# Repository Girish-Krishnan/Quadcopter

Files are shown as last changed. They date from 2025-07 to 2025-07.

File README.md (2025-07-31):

# Quadcopter

*Made by Girish Krishnan and Anish Kulkarni*

---

Open-source hardware and firmware for a compact 4‑rotor UAV.
[**Watch the demo videos on YouTube!**](https://www.youtube.com/playlist?list=PLE_L-WPduPxbYMuvPQKa1v5fUpK1VIxrP)

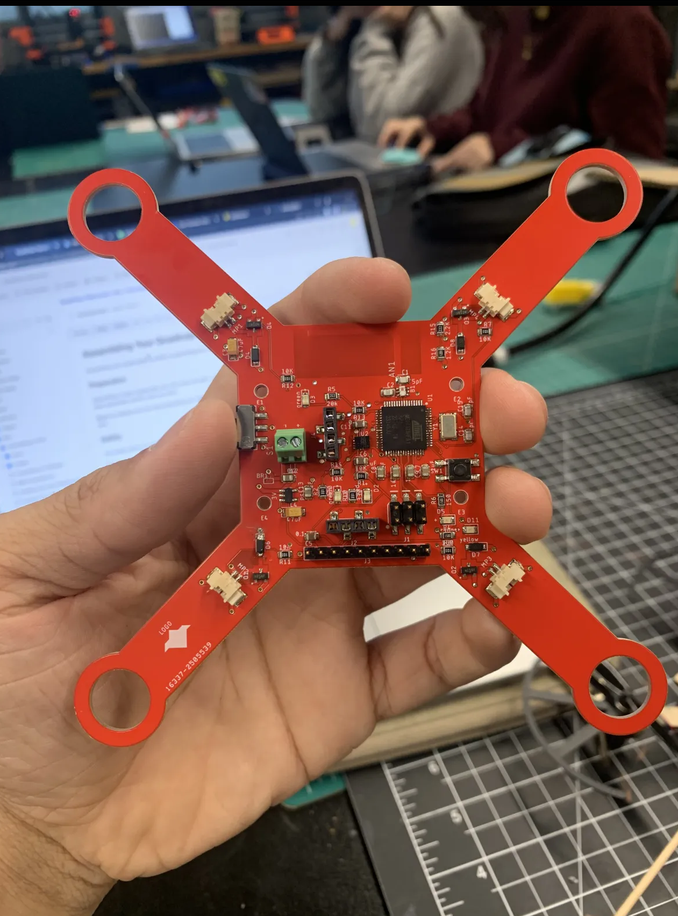
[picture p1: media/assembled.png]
Assembled Quadcopter
|PID Tuning Animation| |
|---|---|

This project contains hardware and firmware for a custom 4‑rotor UAV. The design is based on the ATmega128RFA1 microcontroller which integrates a 2.4 GHz radio. The repository includes the printed circuit board layout, flight controller firmware, and code for a handheld remote.

## Table of Contents
- [Quadcopter](#quadcopter)
  - [Table of Contents](#table-of-contents)
  - [Features](#features)
  - [System Overview](#system-overview)
  - [Repository Layout](#repository-layout)
  - [Hardware Overview](#hardware-overview)
  - [Firmware Overview](#firmware-overview)
    - [Wireless Protocol](#wireless-protocol)
    - [Flight Controller (`quad_flight.ino`)](#flight-controller-quad_flightino)
    - [Remote Firmware (`remote_firmware.ino`)](#remote-firmware-remote_firmwareino)
    - [PID Control Loops](#pid-control-loops)
  - [Building and Uploading](#building-and-uploading)
  - [License](#license)
  - [References](#references)

## Features
- Flight controller based on the ATmega128RFA1 with integrated 2.4 GHz radio
- Handheld remote with dual gimbals, LCD and menu navigation
- Telemetry link for battery monitoring and state feedback
- PID tuning directly from the remote
- Four-layer PCB with on-board ESC drivers and IMU

## System Overview

The project consists of two main pieces of hardware:

1. **Quadcopter** – a compact flight controller board driving four brushless motors via electronic speed controllers (ESCs).
2. **Remote** – a handheld transmitter with gimbal sticks, buttons and an LCD that sends pilot commands over 2.4 GHz.

The diagram below summarizes the high–level flow of data and control.

```mermaid
graph LR
    Remote[(Handheld Remote)] -- 2.4GHz --> MCU[ATmega128RFA1]
    MCU --> IMU[LSM6DSOX IMU]
    MCU --> ESCs
    ESCs --> Motors
    MCU -- Telemetry --> Remote
```

## Repository Layout

```
firmware/              Embedded source code and Arduino libraries
hardware/              EAGLE schematic/board files and CAM outputs
```

Key firmware sketches:

- `quad_flight/quad_flight.ino` – flight controller running on the quadcopter
- `remote_firmware/remote_firmware.ino` – transmitter with LCD and gimbals

## Hardware Overview

The quadcopter PCB is a four‑layer board measuring 119×119 mm with red soldermask and white silkscreen【F:hardware/metadata.txt†L1-L4】. Major components:

- **ATmega128RFA1** MCU with onboard 2.4 GHz transceiver
- **LSM6DSOX** IMU for 3‑axis gyro and accelerometer
- FET motor drivers for four brushless ESCs
- Power regulation, battery monitor (via `BAT_SENSE_PIN`), and status LEDs
- Connectors for an external receiver and programming headers

EAGLE design files are under `hardware/` and the manufacturing CAM outputs are zipped as `quadcopter.cam.zip`.

The `hardware/QuadClass_Atmega128RFA_Arduino_Addon` folder contains board definitions so the Arduino IDE can program the ATmega128RFA1 board. Copy this directory into the `hardware` folder of your Arduino sketchbook to install the board support.

Here is a schematic overview of the quadcopter:

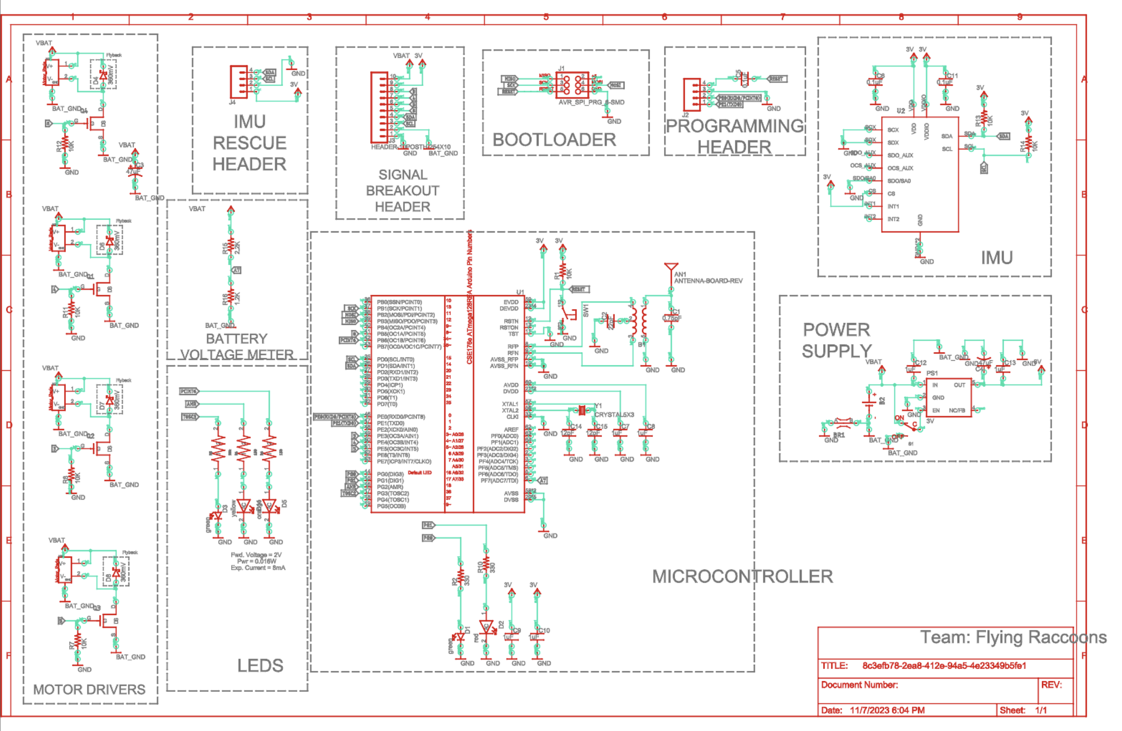
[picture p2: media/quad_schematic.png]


Here is the layout of the quadcopter PCB, showing the placement of components and routing:

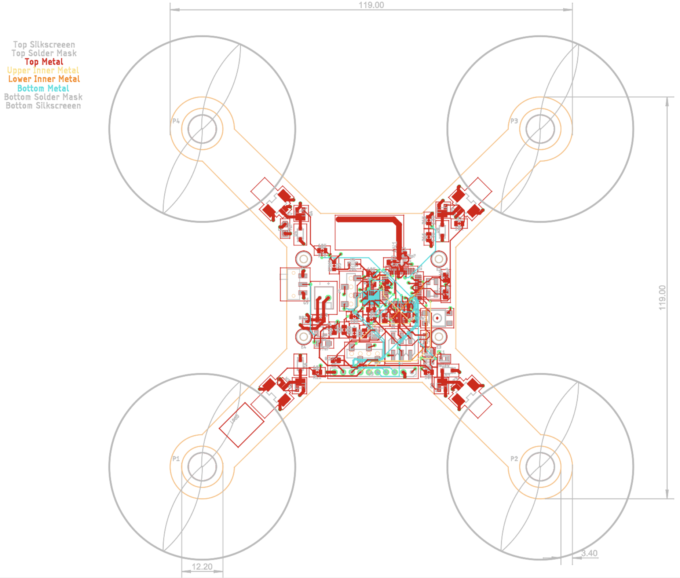
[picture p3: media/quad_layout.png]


Here are pictures of the top and bottom layers of the PCB:

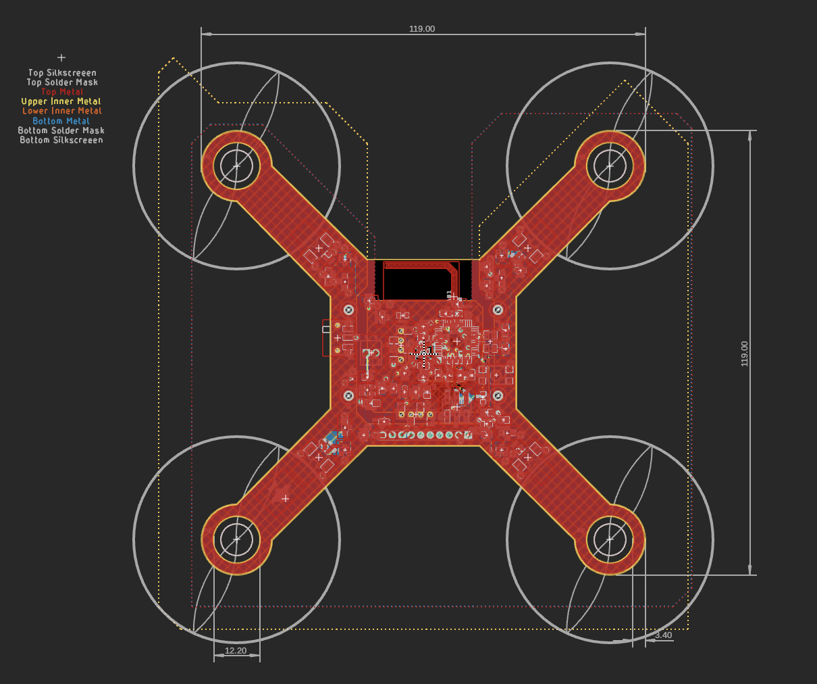
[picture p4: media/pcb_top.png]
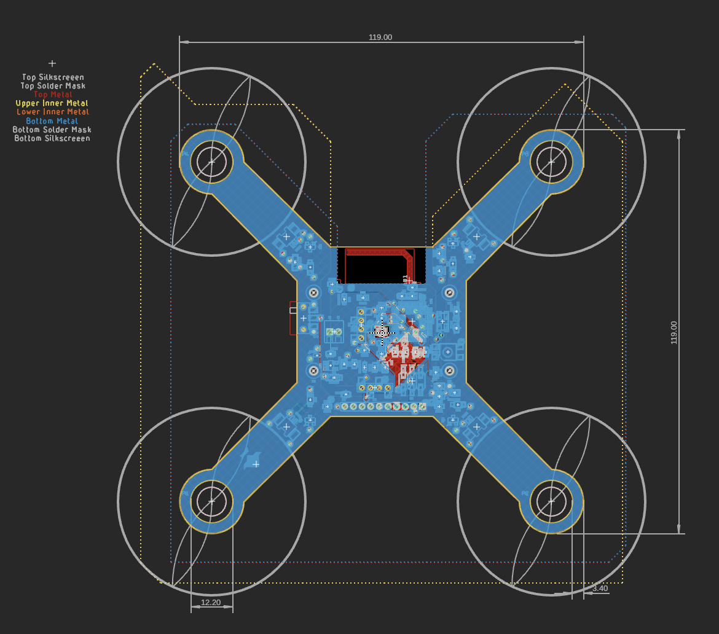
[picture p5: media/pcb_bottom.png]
|||
|---|---|
| Top Layer | Bottom Layer |

## Firmware Overview

### Wireless Protocol

The on-board radio communicates with the remote using packets defined in `Wireless_Packet.h`:

```cpp
struct Packet {
    uint8_t magicNumber;
    uint8_t roll, pitch, yaw, throttle;
    double  Kp_pitch, Ki_pitch, Kd_pitch;
    double  Kp_roll,  Ki_roll,  Kd_roll;
    double  Kp_yaw,   Ki_yaw,   Kd_yaw;
    uint8_t batteryVoltage;
    int     trims[3];
    uint8_t state;
    uint8_t checksum;
};
```
【F:firmware/libraries/Wireless_Packet/Wireless_Packet.h†L1-L34】

Packets carry user commands, PID gains, trims, and telemetry such as battery level. Communication occurs on channel&nbsp;20 by default.

### Flight Controller (`quad_flight.ino`)

The flight controller reads the LSM6DSOX IMU using the Adafruit AHRS library. A complementary filter and PID loop produce motor outputs:

- Desired roll/pitch/yaw are received from the remote.
- IMU data is converted to angles and rates.
- Proportional, integral and derivative terms are computed every loop.
- Four PWM outputs drive the motors via `spinMotors()` which mixes PID outputs to each rotor.

State transitions (`DISARMED`, `ARMED`, `QUAD_RESET`) are received wirelessly. The code also reports back battery percentage every second.

### Remote Firmware (`remote_firmware.ino`)

The remote uses analog gimbals, push buttons, a rotary encoder and a SerLCD display. It calibrates the joystick range to map raw ADC values to 0–255 and stores them in EEPROM【F:firmware/remote_firmware/remote_firmware.ino†L240-L314】. In the armed state, pressing the encoder or buttons adjusts trim values which are sent in each packet.

Incoming packets from the quad provide its state and battery status so the remote can display feedback to the user.

The remote hardware exposes the following controls:

- Two gimbal sticks (yaw/throttle and roll/pitch) wired to analog inputs A0–A3.
- A rotary encoder with push‑button for menu navigation.
- Five directional buttons for trims and menu actions.
- A small serial LCD showing mode and battery levels.

All pins are defined in `quad_remote.h` under the `Remote` library.

### PID Control Loops

Here is the setup used for tuning the PID for the roll and pitch axes:

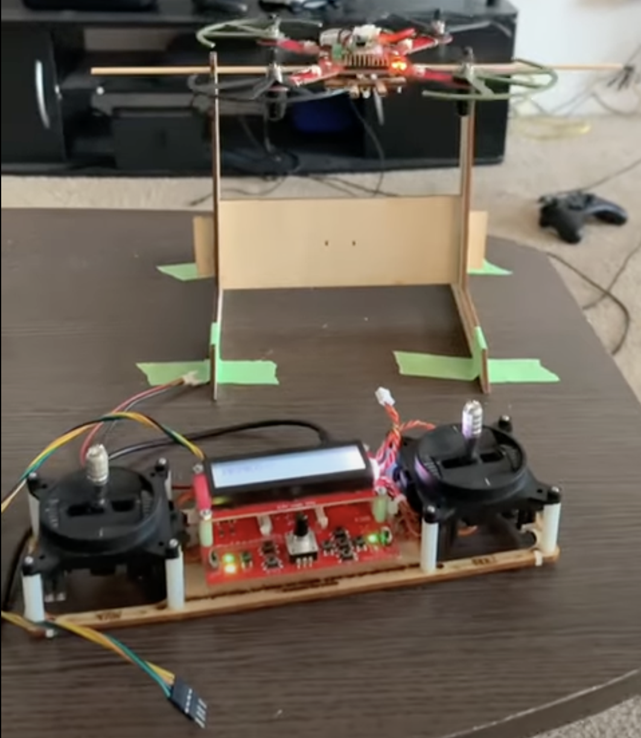
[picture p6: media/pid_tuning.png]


The flight controller stabilizes the aircraft using three independent PID loops
for roll, pitch and yaw. Error values are computed from the difference between
the desired setpoint (received from the remote) and the measured angle or rate
from the IMU. Each loop produces a correction that is mixed into the individual
motor commands.

```mermaid
graph TD
    R[Remote input] -->|setpoint| E[Error]
    IMU -- feedback --> E
    E --> P[P gain]
    E --> I[I gain]
    E --> D[D gain]
    P --> SUM
    I --> SUM
    D --> SUM
    SUM --> MIX(Motor Mixer)
    MIX --> Motors
```

## Building and Uploading

1. Install the Arduino IDE.
2. Copy `firmware/hardware/QuadClass_Atmega128RFA_Arduino_Addon` to your Arduino `hardware/` directory and restart the IDE. Select **Quad Class ATmega128RFA1 Boards** under *Tools → Board*.
3. Copy the libraries from `firmware/libraries` into your Arduino `libraries/` directory.
4. Open `firmware/quad_flight/quad_flight.ino` to build the flight controller or `firmware/remote_firmware/remote_firmware.ino` for the remote.
5. Connect the ATmega128RFA1 board via USB and upload using the standard Arduino bootloader.

## License

This project is released under the MIT License; see [LICENSE](LICENSE) for details.

## References

- [NVSL QuadClass Resources](https://github.com/NVSL/QuadClass-Resources/tree/master)

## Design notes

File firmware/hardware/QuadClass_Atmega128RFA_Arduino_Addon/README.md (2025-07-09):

# Arduino Board definitions for the ATmega128RFA1-based boards

This folder should be added to a *hardware* directory within your Arduino sketchbook. Normally the sketchbook will install to your documents/Arduino folder. If a *hardware* folder isn't already there, make it.

This directory contains a *boards.txt* file which defines how Arduino will handle ATmega128RFA1-based boards for the Quadcopter Class, and adds a selectable option under the *Tools > Board* menu. When you open the Arduino ID (close and reopen if it's already open), this option should be added to the menu.

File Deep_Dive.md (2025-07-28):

# Quadcopter Deep Dive

## Overview

This project implements an open‑source four‑rotor UAV platform. The repository contains the complete firmware for both flight controller and remote as well as hardware designs for the custom PCB. The microcontroller at the heart of both devices is the Atmel ATmega128RFA1 which integrates a 2.4&nbsp;GHz radio allowing wireless control and telemetry.

The codebase is organized under `firmware/` for all sketches and reusable libraries while `hardware/` holds EAGLE board/schematic files. The root [README](README.md) provides a high‑level summary and diagrams of the system architecture. Key highlights include support for PID tuning via the remote and telemetry reporting from the quadcopter back to the handheld controller.

This document dives into the design and implementation details of the project, covering hardware features, data structures, algorithms, and how the pieces interact.

## Hardware Design

### Board Metadata

The quadcopter PCB is a four‑layer board with dimensions of 119&nbsp;×&nbsp;119&nbsp;mm using red soldermask and white silkscreen as recorded in `hardware/metadata.txt`:

```text
Color: Red
Silkscreen colors: White
Dimensions: 119mm x 119mm
```
【F:hardware/metadata.txt†L1-L4】

### Major Components

* **ATmega128RFA1** – integrates an AVR CPU with a low‑power 2.4&nbsp;GHz transceiver.
* **LSM6DSOX IMU** – provides 3‑axis gyroscope and accelerometer data.
* FET motor drivers for the four ESC channels.
* Battery monitor on analog pin `BAT_SENSE_PIN`.
* Status LEDs and programming connectors.

The board and schematic files (`quadcopter.sch`, `quadcopter.brd`) can be opened in EAGLE for detailed component placement and routing inspection.

## Firmware Structure

The `firmware/` directory contains a number of Arduino sketches:

```
RFChat/        – radio terminal test
RFCount/       – simple counting transmitter
RFEcho/        – echo received bytes
RFPing/        – radio link ping utility
quad_flight/   – flight controller running on the quadcopter
remote_firmware/ – code for the handheld remote
libraries/     – shared driver libraries
```

The two primary sketches used in normal operation are `quad_flight/quad_flight.ino` and `remote_firmware/remote_firmware.ino`. Several custom libraries are included under `firmware/libraries` to abstract radio access, sensor fusion and user input.

### Wireless Packet Protocol

Both sides communicate using a packed C++ struct defined in `Wireless_Packet.h`. Every field of the struct is transmitted over the air, preceded by a magic number and followed by a checksum. The struct layout is reproduced in the README and in the header file:

```cpp
struct Packet {
    uint8_t magicNumber;
    uint8_t roll;
    uint8_t pitch;
    uint8_t yaw;
    uint8_t throttle;
    double Kp_pitch;
    double Ki_pitch;
    double Kd_pitch;
    double Kp_roll;
    double Ki_roll;
    double Kd_roll;
    double Kp_yaw;
    double Ki_yaw;
    double Kd_yaw;
    uint8_t batteryVoltage;
    int trims[3];
    uint8_t state;
    uint8_t checksum;
};
```
【F:firmware/libraries/Wireless_Packet/Wireless_Packet.h†L17-L36】

Two constants distinguish packet origin: `MAGIC_NUMBER_REMOTE` (`223`) and `MAGIC_NUMBER_QUAD` (`154`). The library provides a simple API consisting of `sendPacket`, `receivePacket`, and `calculateChecksum`. `receivePacket` reads bytes from the radio and verifies both checksum and magic number before returning:

```cpp
void Wireless_Packet::sendPacket(const Packet &packet) {
    rfWrite((uint8_t *)&packet, sizeof(Packet));
}

bool Wireless_Packet::receivePacket(Packet &packet, bool isRemote) {
    bool verify = false;
    if (rfAvailable() >= sizeof(Packet)) {
        rfRead((uint8_t *)&packet, sizeof(Packet));
        uint8_t checksum = calculateChecksum(packet);
        uint8_t magicNumber = packet.magicNumber;
        if (isRemote)
            verify =  (checksum == packet.checksum) && (magicNumber == MAGIC_NUMBER_QUAD);
        else
            verify =  (checksum == packet.checksum) && (magicNumber == MAGIC_NUMBER_REMOTE);
    }
    if (!verify) {
        rfFlush();
    }
    return verify;
}
```
【F:firmware/libraries/Wireless_Packet/Wireless_Packet.cpp†L1-L26】

Checksum generation is a simple XOR of all preceding bytes.

### Radio Driver

The `Radio` library (based on SparkFun code for the ATmega128RFA1) initializes the transceiver, sends and receives frames and implements ring‑buffer management. Functions such as `rfWrite` and `rfRead` handle arbitrary byte sequences while hardware interrupts fill the receive buffer. See `radio.cpp` for the full implementation.

### Remote Firmware

The handheld remote houses two analog gimbals (four axes), a rotary encoder, a directional button pad and a serial LCD. On boot, `remote_firmware.ino` calls `quad_remote_setup()` which configures pins and interrupts as defined in `quad_remote.h`. Calibration data for joystick min/max values is stored in EEPROM so that analog readings can be mapped to 0–255. During startup the sketch loads this data:

```cpp
CalibrationData calibrationData;
EEPROM.get(0, calibrationData);
if (calibrationData.maxYaw != 0 && calibrationData.maxThrottle != 0 &&
    calibrationData.maxRoll != 0 && calibrationData.maxPitch != 0 &&
    calibrationData.minYaw != 1023 && calibrationData.minThrottle != 1023 &&
    calibrationData.minRoll != 1023 && calibrationData.minPitch != 1023) {
  maxYaw = calibrationData.maxYaw;
  maxThrottle = calibrationData.maxThrottle;
  maxRoll = calibrationData.maxRoll;
  maxPitch = calibrationData.maxPitch;
  minYaw = calibrationData.minYaw;
  minThrottle = calibrationData.minThrottle;
  minRoll = calibrationData.minRoll;
  minPitch = calibrationData.minPitch;
}
```
【F:firmware/remote_firmware/remote_firmware.ino†L104-L116】

During operation the remote repeatedly reads the gimbals, maps them to 8‑bit values and constructs an outgoing packet containing pilot commands, PID gains (which can be set over the serial port) and trim adjustments. The packet is then checksummed and sent via the radio:

```cpp
Packet packetToSend = {MAGIC_NUMBER_REMOTE, 0, 0, 0, 0, 0.0, 0.0, 0.0, 0.0, 0.0, 0.0, 0.0, 0.0, 0.0, 0,
                       {pitchTrim, rollTrim, yawTrim}, state, 0};
packetToSend.pitch = gimballVals[3];
packetToSend.roll = gimballVals[2];
packetToSend.yaw = gimballVals[0];
packetToSend.throttle = gimballVals[1];
packetToSend.Kp_pitch = Kp_pitch;
packetToSend.Ki_pitch = Ki_pitch;
packetToSend.Kd_pitch = Kd_pitch;
packetToSend.Kp_roll = Kp_roll;
packetToSend.Ki_roll = Ki_roll;
packetToSend.Kd_roll = Kd_roll;
packetToSend.Kp_yaw = Kp_yaw;
packetToSend.Ki_yaw = Ki_yaw;
packetToSend.Kd_yaw = Kd_yaw;
packetToSend.checksum = wirelessPacket.calculateChecksum(packetToSend);
wirelessPacket.sendPacket(packetToSend);
```
【F:firmware/remote_firmware/remote_firmware.ino†L230-L241】

When in calibration mode, raw ADC values are shown on the LCD and the max/min values are updated until the user presses the center button. The resulting ranges are written back to EEPROM:

```cpp
if(is_pressed(BUTTON_CENTER_PIN) && (millis() - centerButtonStartTime > 250)) {
  centerButtonStartTime = millis();
  state = DISARMED;
  CalibrationData calibrationData = {maxYaw, maxThrottle, maxRoll, maxPitch,
                                     minYaw, minThrottle, minRoll, minPitch};
  EEPROM.put(0, calibrationData);
  lcd.clear();
  lcd.home();
  lcd.print("Calib Done!");
  ...
}
```
【F:firmware/remote_firmware/remote_firmware.ino†L300-L308】

Gimbal input mapping is handled by the helper `readGimballs()` which constrains raw readings according to stored min/max and maps them to 0–255:

```cpp
int yaw = map(constrain(analogRead(PIN_YAW), minYaw+15, maxYaw-15), minYaw+15, maxYaw-15, 0, 255);
int throttle = map(constrain(analogRead(PIN_THROTTLE), minThrottle+15, maxThrottle-15), minThrottle+15, maxThrottle-15, 0, 255);
int roll = map(constrain(analogRead(PIN_ROLL), minRoll+15, maxRoll-15), minRoll+15, maxRoll-15, 0, 255);
int pitch = map(constrain(analogRead(PIN_PITCH), minPitch+15, maxPitch-15), minPitch+15, maxPitch-15, 0, 255);
gimballArr[0] = yaw;
gimballArr[1] = throttle;
gimballArr[2] = roll;
gimballArr[3] = pitch;
```
【F:firmware/remote_firmware/remote_firmware.ino†L449-L457】

### Flight Controller Firmware

The flight controller sketch, `quad_flight.ino`, initializes the radio and the LSM6DSOX IMU, then calibrates the sensor offsets. Using the Adafruit AHRS library, it obtains roll and pitch angles plus gyro rates. A complementary filter mixes gyro rates with measured angles to produce smoothed estimates. The controller maintains PID variables for all three axes.

During `loop()`, received packets provide desired pitch/roll/yaw inputs as well as updated PID coefficients. The incoming packet processing ensures state transitions are stable by requiring several consistent packets before changing modes.

IMU readings are converted to rates and angles, offsets subtracted, and then the complementary filter updates the current orientation. The PID controller then computes corrections and sends commands to the four motors via `spinMotors()`.

The `spinMotors` function prevents output saturation by scaling throttle if any motor would exceed the allowable PWM range. The implementation is:

```cpp
void spinMotors(int throttle, int control_output_roll, int control_output_pitch, int control_output_yaw) {
    if (throttle < 5) {
        analogWrite(MOTOR1, 0);
        analogWrite(MOTOR2, 0);
        analogWrite(MOTOR3, 0);
        analogWrite(MOTOR4, 0);
    } else {
        int pid1 = control_output_roll - control_output_pitch - control_output_yaw;
        int pid2 = control_output_roll + control_output_pitch + control_output_yaw;
        int pid3 = -control_output_roll + control_output_pitch - control_output_yaw;
        int pid4 = -control_output_roll - control_output_pitch + control_output_yaw;

        int max_pid = max(max(pid1, pid2), max(pid3, pid4));
        int adjusted_throttle = throttle;
        if (max_pid + throttle > 255) {
            adjusted_throttle = 255 - max_pid;
        }

        int motor1_val = constrain(adjusted_throttle + pid1, 0, 255);
        int motor2_val = constrain(adjusted_throttle + pid2, 0, 255);
        int motor3_val = constrain(adjusted_throttle + pid3, 0, 255);
        int motor4_val = constrain(adjusted_throttle + pid4, 0, 255);

        analogWrite(MOTOR1, motor1_val);
        analogWrite(MOTOR2, motor2_val);
        analogWrite(MOTOR3, motor3_val);
        analogWrite(MOTOR4, motor4_val);
    }
}
```
【F:firmware/quad_flight/quad_flight.ino†L497-L531】

Battery voltage monitoring is performed with `readBatteryPercentage` which maps the analog reading between calibrated limits to 0‑100%:

```cpp
int readBatteryPercentage() {
  int raw = analogRead(BAT_SENSE_PIN);
  return map(constrain(raw, lowerBatteryLimit, upperBatteryLimit), lowerBatteryLimit, upperBatteryLimit, 0, 100);
}
```
【F:firmware/quad_flight/quad_flight.ino†L568-L571】

### Sensor Fusion Library

The included `QuadClass_AHRS` library is derived from Adafruit’s AHRS algorithms. The `Adafruit_Simple_AHRS` class converts accelerometer and gyroscope readings into Euler angles. `getQuadOrientation` returns `quad_data_t` which includes roll/pitch angles and rotational rates:

```cpp
typedef struct {
     float roll;
     float pitch;
     float roll_rate;
     float pitch_rate;
     float yaw_rate;
} quad_data_t;
```
【F:firmware/libraries/QuadClass_AHRS/src/Adafruit_Simple_AHRS.h†L10-L18】

The library computes pitch and roll from accelerometer data and outputs degrees along with gyro rates, allowing the main firmware to implement the complementary filter and PID loops.

## Remote Input Handling Library

`quad_remote.cpp` sets up the rotary encoder and button interrupts. It defines arrays of pin numbers and labels for all 14 input channels. Interrupt service routines call customizable callbacks when buttons change state so the main firmware can react immediately. The remote uses the `SoftwareSerial2` library to communicate with the serial LCD.

## Safety and Reliability Considerations

* **Checksum Verification** – All radio packets are XOR‑checksummed (see `calculateChecksum`) to detect corruption. Non‑matching packets are discarded and the radio buffer is flushed to prevent stale data being used.
* **Magic Numbers** – `MAGIC_NUMBER_REMOTE` and `MAGIC_NUMBER_QUAD` prevent cross‑talk with other devices and catch mis‑aligned packets.
* **Ring Buffer** – The radio driver uses a 127‑byte ring buffer and interrupt handlers to capture incoming frames without blocking the main loop. Functions such as `rfAvailable` and `rfRead` manage head/tail pointers safely.
* **Throttle Clamping** – `spinMotors` scales down throttle if any motor would exceed 255 ensuring PWM outputs stay within range and maintain control authority.
* **State Machine** – Both remote and quad track states (`DISARMED`, `ARMED`, `CALIBRATION`, `QUAD_RESET`) to avoid spurious motor activation. The flight controller requires multiple identical state packets before changing state to avoid glitching due to packet loss.
* **PID Wind‑up Protection** – Integral terms are cleared when throttle is low or the respective Ki gain is nearly zero, preventing runaway accumulation while the quad is idle.

## Building and Uploading

To compile either firmware sketch you must install the Arduino IDE, copy the board support package from `hardware/QuadClass_Atmega128RFA_Arduino_Addon` into your Arduino hardware directory, and copy the libraries inside `firmware/libraries` to your Arduino `libraries` folder. Building `quad_flight/quad_flight.ino` targets the quadcopter; `remote_firmware/remote_firmware.ino` builds the remote. Uploads are performed via the standard Arduino bootloader over USB.

## Conclusion

The repository implements a full small‑scale UAV stack. The combination of custom hardware, wireless packet protocol and PID‑based stabilization provides a solid foundation for experimentation. The remote’s ability to tune PID parameters in flight and store joystick calibration data in EEPROM makes the platform versatile and easy to adjust.

Telemetry such as battery level and state feedback ensures the operator stays informed of system status. All code is written in C++ using the Arduino framework, making it straightforward to extend or modify.

This deep dive should provide a thorough understanding of how the project components fit together, how data flows from the user inputs to the motors, and how safety is maintained throughout the codebase.

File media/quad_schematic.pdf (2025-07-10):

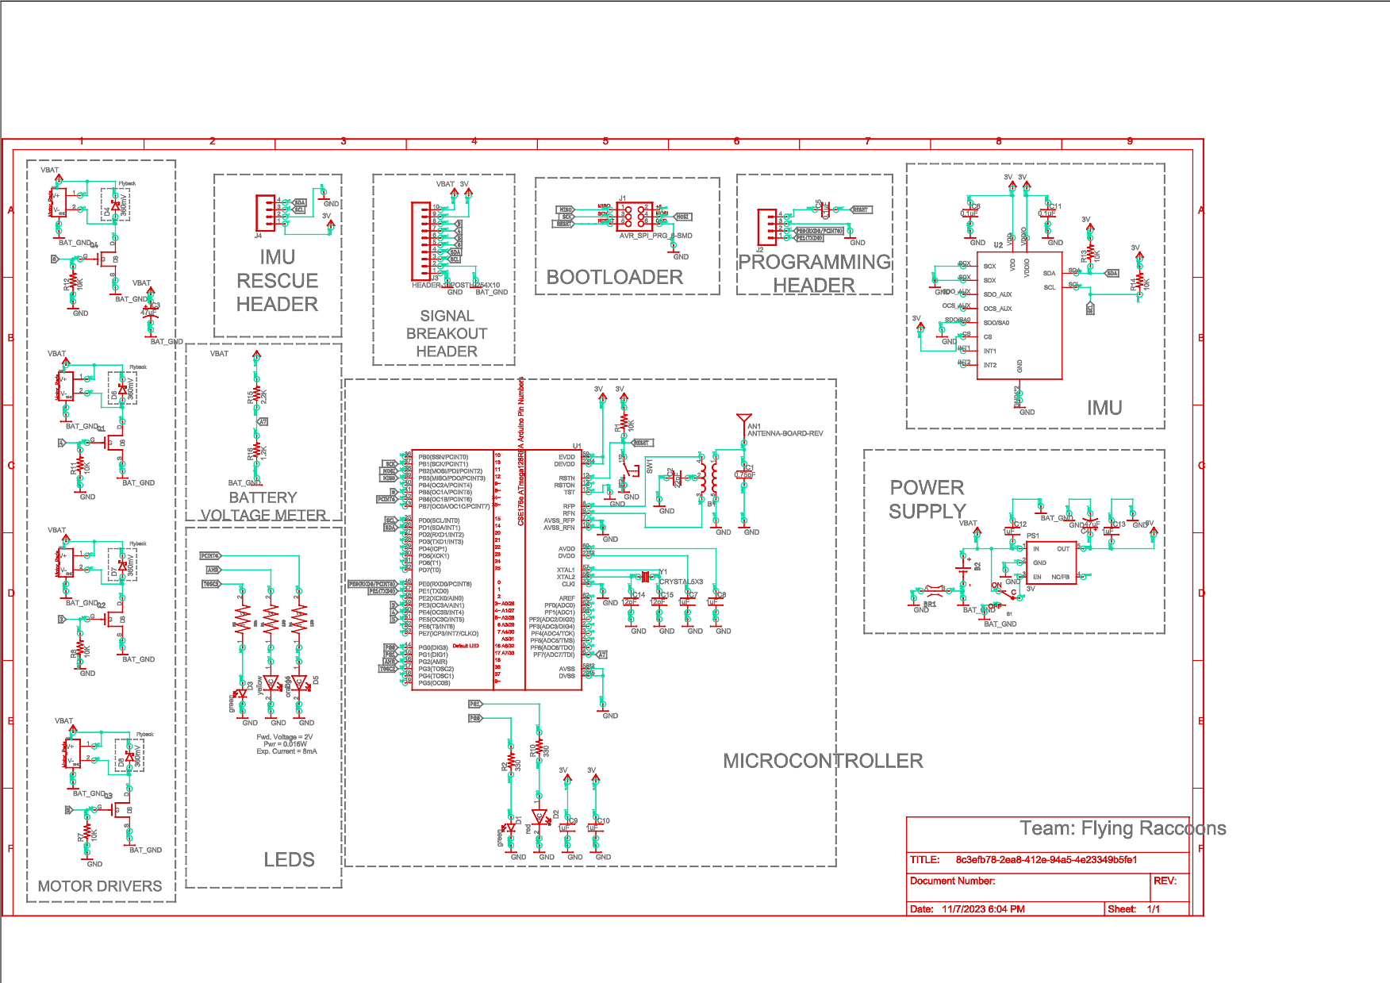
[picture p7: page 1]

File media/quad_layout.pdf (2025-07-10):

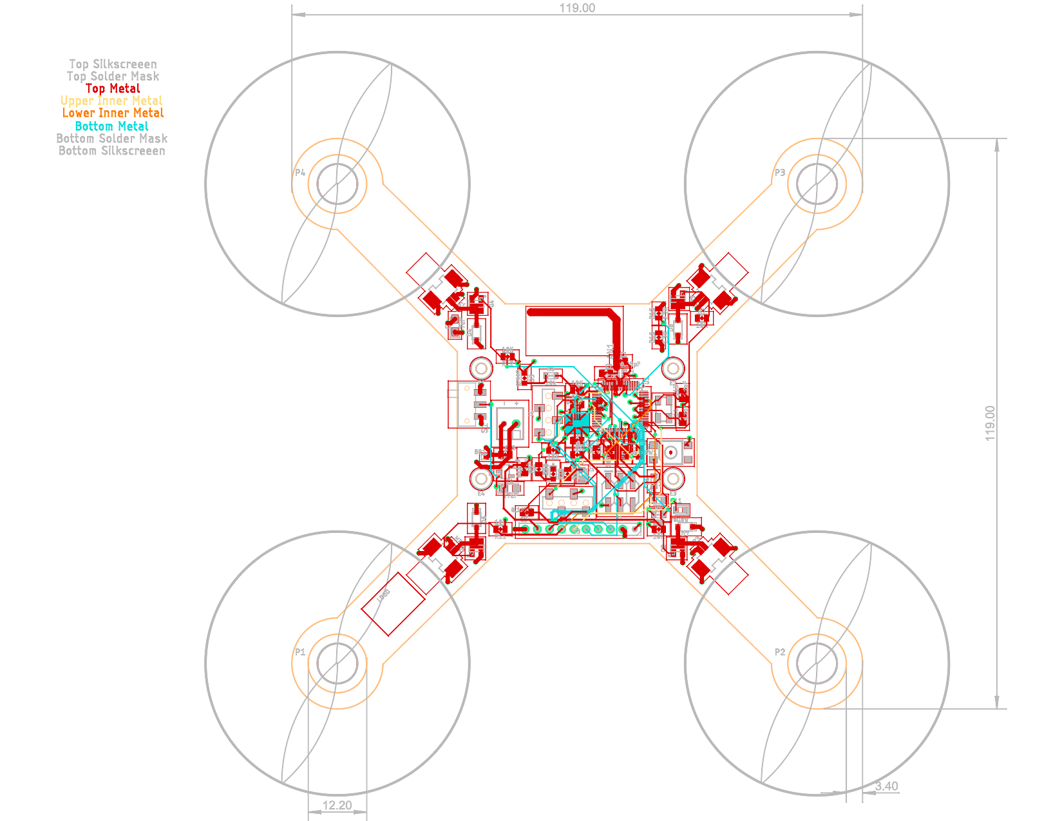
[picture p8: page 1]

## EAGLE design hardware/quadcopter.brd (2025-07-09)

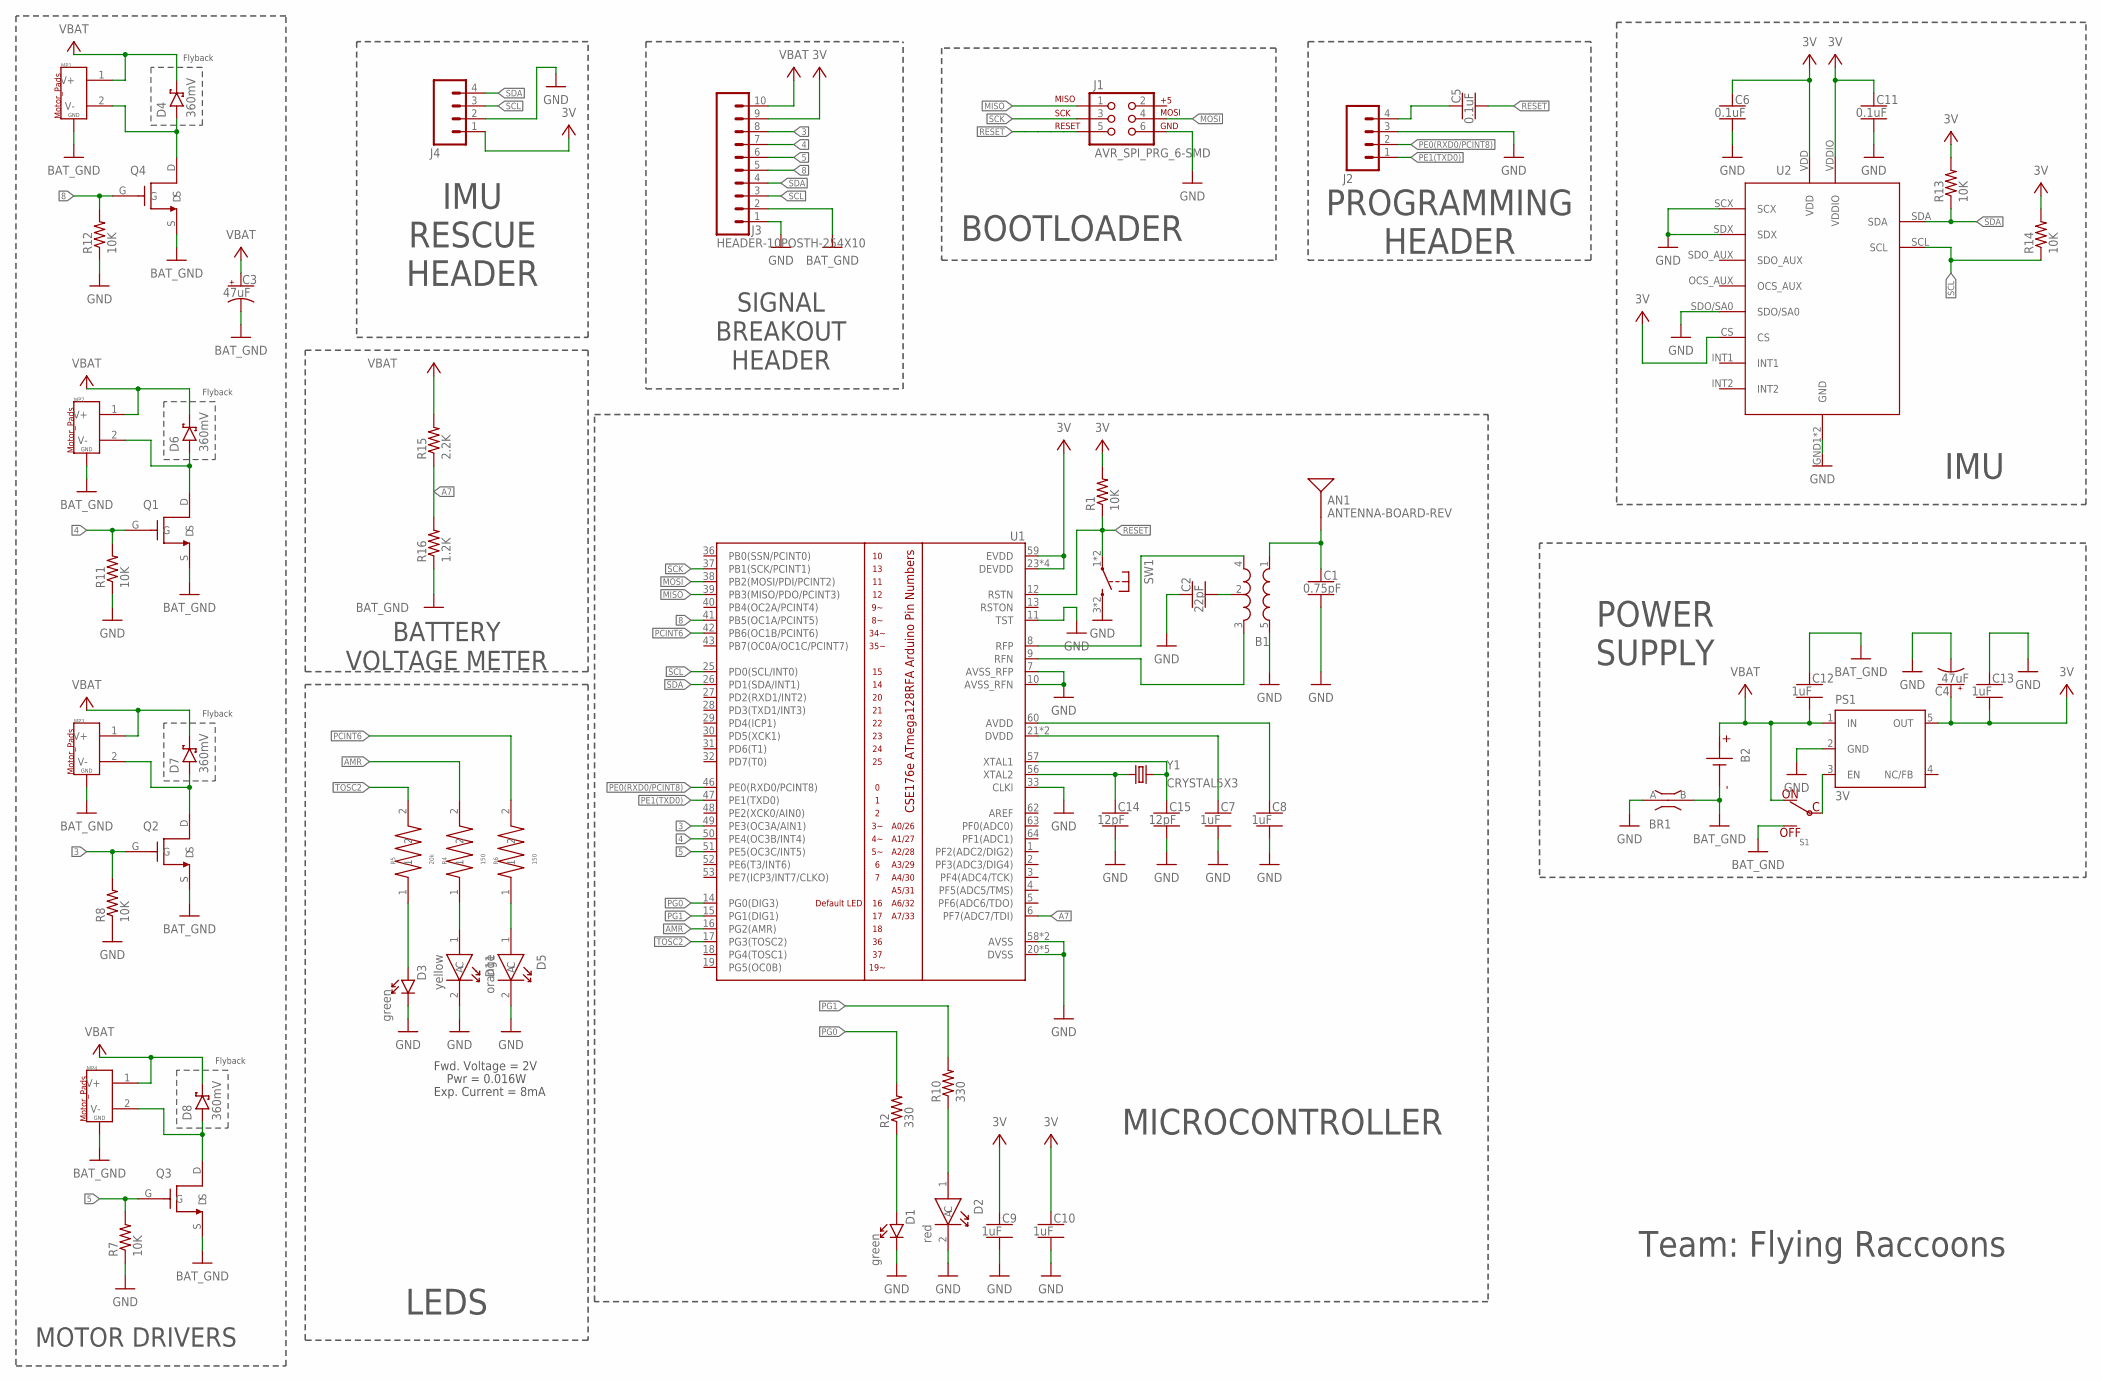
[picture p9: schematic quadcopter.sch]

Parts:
AN1: ANTENNA-BOARD-REV; ANT_PCB_2.4GHZ_NRF8001_1.6MM_1OZ_REV
B1: BALUN0805; BALUN
B2: BATTERY-SCREW-TERMINAL; SCREW-TERMINAL-1X2-2.54MM
BR1: NET_BRIDGE-NET-BRIDGE; BRIDGE
C1: 0.75pF; CAPC2012X140_HS
C2: 22pF; CAPC2012X140_HS
C3, C4: 47uF; CAPMP3216X180
C5, C6, C11: 0.1uF; CAPC2012X140_HS
C7, C8, C9, C10, C12, C13: 1uF; CAPC2012X140_HS
C14, C15: 12pF; CAPC2012X140_HS
D1, D3: green; LEDSC125X200X120-2_HS
D2: red; LED-LTST-C170EKT
D4, D6, D7, D8: 360mV; SODFL3516X96
D5: orange; LED-LTST-C170EKT
D11: yellow; LED-LTST-C170EKT
J1: AVR_SPI_PRG_6-SMD; 2X3-SMD
J2, J4: HEADER-4POS-0.1IN-FEMALE-SMD-BOTTOM-ENTRY; HEADER-1X4-BOTTOM-ENTRY
J3: HEADER-10POSTH-254X10; HDRV10W63P254_10X1_2540X254H838_HS
MP1, MP2, MP3, MP4: MOTOR_PADS_GND-MOLEX-SMD; MOLEX-0532610271
PS1: 3V; SOT23-DBV
Q1, Q2, Q3, Q4: NMOSFET; SOTFL95P237X112-3N
R1, R7, R8, R11, R12, R13, R14: 10K; RESC2012X60_HS
R2, R10: 330; RESC2012X60_HS
R4, R6: 150; 0805_RESISTOR
R5: 20k; 0805_RESISTOR
R15: 2.2K; RESC2012X60_HS
R16: 1.2K; RESC2012X60_HS
S1: POWER-SWITCH-MFS201N-9-Z-SMD-EDGE; JS102011SAQN
SW1: PUSHBUTTON_-4.5X4.5; 4.5MM_TACTILE_SWITCH_TL3305AF160QG
U1: ATMEGA128RFA1; QFN-64
U2: IMU_LSM6DS0XTR-IMU-LSM6DS0XTR; IMU_LSM6DS0XTR
Y1: CRYSTAL5X3; CRYSTAL-SMD-5X3

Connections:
3: J3.8, Q2.G, R8.2, U1.49 (PE3(OC3A/AIN1))
3V: C4.1 (+), C6.1, C9.1, C10.1, C11.1, C13.2, J3.9, J4.1, PS1.5 (OUT), R1.2, R13.2, R14.2, U1.23 (DEVDD), U1.34 (DEVDD), U1.44 (DEVDD), U1.54 (DEVDD), U1.59 (EVDD), U2.CS, U2.VDD, U2.VDDIO
4: J3.7, Q1.G, R11.2, U1.50 (PE4(OC3B/INT4))
5: J3.6, Q3.G, R7.2, U1.51 (PE5(OC3C/INT5))
8: J3.5, Q4.G, R12.2, U1.41 (PB5(OC1A/PCINT5))
A7: R15.1, R16.2, U1.6 (PF7(ADC7/TDI))
AMR: R4.2, U1.16 (PG2(AMR))
BAT_GND: B2.1 (N), BR1.B, C3.2 (-), C12.1, J3.2, MP1.G1 (GND), MP1.G2 (GND), MP2.G1 (GND), MP2.G2 (GND), MP3.G1 (GND), MP3.G2 (GND), MP4.G1 (GND), MP4.G2 (GND), Q1.S, Q2.S, Q3.S, Q4.S, R16.1, S1.A (OFF)
GND: B1.5 (GND), BR1.A, C1.2, C2.1, C4.2 (-), C6.2, C7.2, C8.2, C9.2, C10.2, C11.2, C13.1, C14.2, C15.2, D1.C, D2.2 (C), D3.C, D5.2 (C), D11.2 (C), J1.6, J2.3, J3.1, J4.2, PS1.2 (GND), R7.1, R8.1, R11.1, R12.1, SW1.3 (2), SW1.4 (2), U1.7 (AVSS_RFP), U1.10 (AVSS_RFN), U1.11 (TST), U1.20 (DVSS), U1.24 (DVSS), U1.33 (CLKI), U1.35 (DVSS), U1.45 (DVSS), U1.55 (DVSS), U1.58 (AVSS), U1.61 (AVSS), U2.GND1 (GND), U2.GND2 (GND), U2.SCX, U2.SDO/SA0, U2.SDX
MISO: J1.1, U1.39 (PB3(MISO/PDO/PCINT3))
MOSI: J1.4, U1.38 (PB2(MOSI/PDI/PCINT2))
unnamed: B1.4 (OUT1), U1.8 (RFP)
unnamed: C15.1, U1.57 (XTAL1), Y1.3 (2)
unnamed: C14.1, U1.56 (XTAL2), Y1.1
unnamed: C7.1, U1.21 (DVDD), U1.22 (DVDD)
unnamed: C8.1, U1.60 (AVDD)
unnamed: B1.3 (OUT2), U1.9 (RFN)
unnamed: B1.2 (GND), C2.2
unnamed: AN1.FEED, B1.1 (IN), C1.1
unnamed: D1.A, R2.1
unnamed: D2.1 (A), R10.1
unnamed: PS1.3 (EN), S1.C
unnamed: D3.A, R5.1
unnamed: D11.1 (A), R4.1
unnamed: D5.1 (A), R6.1
unnamed: C5.1, J2.4
unnamed: D6.2 (A), MP2.2 (V-), Q1.D
unnamed: D7.2 (A), MP3.2 (V-), Q2.D
unnamed: D8.2 (A), MP4.2 (V-), Q3.D
unnamed: D4.2 (A), MP1.2 (V-), Q4.D
PCINT6: R6.2, U1.42 (PB6(OC1B/PCINT6))
PE0(RXD0/PCINT8): J2.2, U1.46 (PE0(RXD0/PCINT8))
PE1(TXD0): J2.1, U1.47 (PE1(TXD0))
PG0: R2.2, U1.14 (PG0(DIG3))
PG1: R10.2, U1.15 (PG1(DIG1))
RESET: C5.2, J1.5, R1.1, SW1.1, SW1.2 (1), U1.12 (RSTN)
SCK: J1.3, U1.37 (PB1(SCK/PCINT1))
SCL: J3.3, J4.3, R14.1, U1.25 (PD0(SCL/INT0)), U2.SCL
SDA: J3.4, J4.4, R13.1, U1.26 (PD1(SDA/INT1)), U2.SDA
TOSC2: R5.2, U1.17 (PG3(TOSC2))
VBAT: B2.2, C3.1 (+), C12.2, D4.1 (C), D6.1 (C), D7.1 (C), D8.1 (C), J3.10, MP1.1 (V+), MP2.1 (V+), MP3.1 (V+), MP4.1 (V+), PS1.1 (IN), R15.2, S1.B (ON)

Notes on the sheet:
IMU
BOOTLOADER
Flyback
MOTOR DRIVERS
SIGNAL BREAKOUT HEADER
IMU RESCUE HEADER
MICROCONTROLLER
POWER SUPPLY
PROGRAMMING HEADER
LEDS
BATTERY VOLTAGE METER
Team: Flying Raccoons
Fwd. Voltage = 2V
Pwr = 0.016W
Exp. Current = 8mA

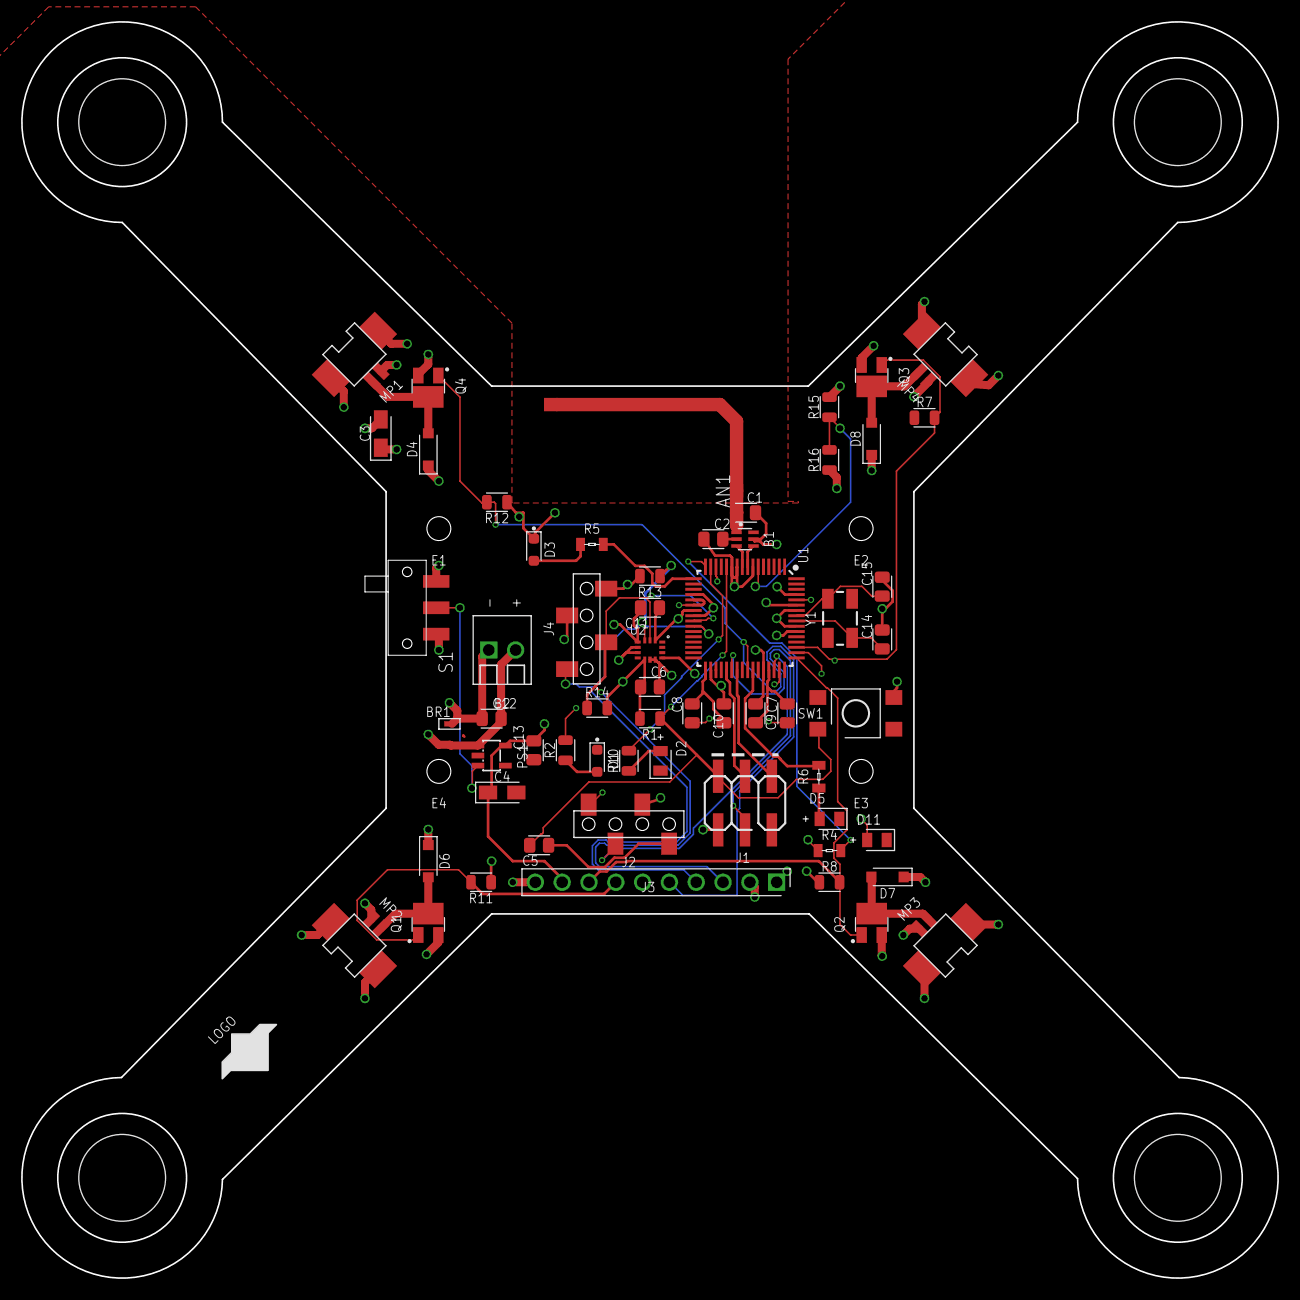
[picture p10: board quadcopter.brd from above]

Board: 4 copper layers, 119.0 x 119.0 mm, 70 parts (0 on the bottom side), 41 nets.

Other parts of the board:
E1, E2, E3, E4: 2-56-MOUNTING-HOLE-NO-METAL
E$1: LAYER_LABELS
LOGO: DECORATIONS
P1, P2, P3, P4: MOTOR_AND_PROP

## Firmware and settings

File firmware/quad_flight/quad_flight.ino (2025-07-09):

#include "radio.h"
#include <Wireless_Packet.h>
#include <Wire.h>
#include <Adafruit_Sensor.h>
#include <QuadClass_LSM6DSOX.h>
#include <Adafruit_Simple_AHRS.h>
Wireless_Packet wirelessPacket;
#define RAD_TO_DEG 57.295779513082320876798154814105
#define CALIBRATION_SAMPLES 50

// REF DESIGN
// const int MOTOR1 = 8; // BLUE
// const int MOTOR2 = 3; // RED
// const int MOTOR3 = 4; // GREEN
// const int MOTOR4 = 5; // UN

// OUR QUADCOPTER
// when the quad is upside down...
// spinning 1 and 3 -> clockwise rotation
// spinning 2 and 4 -> counter clockwise rotation
const int MOTOR1 = 8; // BLUE
const int MOTOR2 = 4; // RED
const int MOTOR3 = 3; // GREEN
const int MOTOR4 = 5; // UN

// LEDs
const int LED_1 = 16; 
const int LED_2 = 17; 
const int LED_3 = 18; 
const int LED_4 = 36;
const int PRETTY_LEDS = 34;

// Battery Voltage
const int BAT_SENSE_PIN = A7;
const int lowerBatteryLimit = 490;
const int upperBatteryLimit = 887;

// State
State state = DISARMED;
State prevState = DISARMED;
bool resetMode = true;

// other variables
int remoteThrottle = 0;
int remoteRoll = 0;
int remotePitch = 0;
int remoteYaw = 0;
int pitchTrim = 0;
int rollTrim = 0;
int yawTrim = 0;
int countStateChange = 0;

// Create LSM9DS0 board instance.
QuadClass_LSM6DSOX lsm = QuadClass_LSM6DSOX();
Adafruit_Simple_AHRS *ahrs = NULL;
Adafruit_Sensor *_accel = NULL;
Adafruit_Sensor *_gyro = NULL;
Adafruit_Sensor *_mag = NULL;  // No Yaw orientation | Always NULL
bool is_calib_IMU = false;

// store initial angle for complementary filter
double cf_pitch = 0.0;
double cf_roll = 0.0;
double cf_yaw = 0.0;

double pitch_angle = 0.0;
double roll_angle = 0.0;
double yaw_angle = 0.0;

double IMU_pitch_offset = 0.0;
double IMU_roll_offset = 0.0;
double IMU_yaw_offset = 0.0;

double IMU_pitch_rate_offset = 0.0;
double IMU_roll_rate_offset = 0.0;
double IMU_yaw_rate_offset = 0.0;

double incoming_pitch = 0.0;
double incoming_roll = 0.0;
double incoming_yaw = 0.0;

double incoming_pitch_rate = 0.0;
double incoming_roll_rate = 0.0;
double incoming_yaw_rate = 0.0;

double gain = 0.92;

// PID
double Kp_roll = 0.0;
double Ki_roll = 0.0;
double Kd_roll = 0.0;

double Kp_pitch = 0.0;
double Ki_pitch = 0.0;
double Kd_pitch = 0.0;

double Kp_yaw = 0.0;
double Ki_yaw = 0.0;
double Kd_yaw = 0.0;

double desired_yaw_rate = 0.0;
double desired_roll = 0.0;
double desired_pitch = 0.0;

double error_roll = 0.0;
double last_error_roll = 0.0;
double sum_error_roll = 0.0;
double derivative_error_roll = 0.0;

double error_pitch = 0.0;
double last_error_pitch = 0.0;
double sum_error_pitch = 0.0;
double derivative_error_pitch = 0.0;

double error_yaw = 0.0;
double last_error_yaw = 0.0;
double sum_error_yaw = 0.0;
double derivative_error_yaw = 0.0;

// Timings
unsigned long timeLastMessage = millis();
unsigned long timeLastSent = millis();
unsigned long lastPIDTime = millis();
unsigned long lastIMU = millis();

void setup() {
  // Serial
  Serial.begin(115200);

  // Battery
  analogReference(INTERNAL);
  pinMode(BAT_SENSE_PIN, INPUT);

  // Motors
  pinMode(MOTOR1, OUTPUT);
  pinMode(MOTOR2, OUTPUT);
  pinMode(MOTOR3, OUTPUT);
  pinMode(MOTOR4, OUTPUT);

  // LEDs
  pinMode(LED_1, OUTPUT);
  pinMode(LED_2, OUTPUT);
  pinMode(LED_3, OUTPUT);
  pinMode(LED_4, OUTPUT);
  pinMode(PRETTY_LEDS, OUTPUT);

  // Radio
  rfBegin(RADIO_CHANNEL);

  // Setup the sensor gain and integration time.
  setupSensor();

  // Set Offset Values
  quad_data_t orientation;
  turnOnLEDs();
  delay(1000);
  turnOffLEDs();
  delay(3000);
  // while(1) {
  //   if (ahrs->getQuadOrientation(&orientation)) {
  //     Serial.println("CALIBRATING...");
  //     IMU_pitch_rate_offset = orientation.pitch_rate;
  //     IMU_roll_rate_offset = orientation.roll_rate;
  //     IMU_yaw_rate_offset = orientation.yaw_rate;

  //     IMU_pitch_offset = orientation.pitch;
  //     IMU_roll_offset = orientation.roll;

  //     Serial.println("Calibrated Values:");
  //     Serial.print("Pitch Rate Offset: ");
  //     Serial.println(IMU_pitch_rate_offset);
  //     Serial.print("Roll Rate Offset: ");
  //     Serial.println(IMU_roll_rate_offset);
  //     Serial.print("Yaw Rate Offset: ");
  //     Serial.println(IMU_yaw_rate_offset);
  //     Serial.print("Pitch Offset: ");
  //     Serial.println(IMU_pitch_offset);
  //     Serial.print("Roll Offset: ");
  //     Serial.println(IMU_roll_offset);
  //     turnOnLEDs();
  //     delay(1000);
  //     turnOffLEDs();
  //     break;
  //   }
  // }

  double pitch_samples[CALIBRATION_SAMPLES];
  double roll_samples[CALIBRATION_SAMPLES];
  double pitch_rate_samples[CALIBRATION_SAMPLES];
  double roll_rate_samples[CALIBRATION_SAMPLES];
  double yaw_rate_samples[CALIBRATION_SAMPLES];

  // Collect samples
  for (int i = 0; i < CALIBRATION_SAMPLES; ++i) {
        quad_data_t orientation;
        while(1) {
        if (ahrs->getQuadOrientation(&orientation)) {
            pitch_samples[i] = orientation.pitch;
            roll_samples[i] = orientation.roll;
            pitch_rate_samples[i] = orientation.pitch_rate;
            roll_rate_samples[i] = orientation.roll_rate;
            yaw_rate_samples[i] = orientation.yaw_rate;
            delay(20); // Delay to allow time between readings
        }
        break;
        }
  }

  findMedian(pitch_samples, CALIBRATION_SAMPLES);
  findMedian(roll_samples, CALIBRATION_SAMPLES);
  findMedian(pitch_rate_samples, CALIBRATION_SAMPLES);
  findMedian(roll_rate_samples, CALIBRATION_SAMPLES);
  findMedian(yaw_rate_samples, CALIBRATION_SAMPLES);

  IMU_pitch_offset = pitch_samples[CALIBRATION_SAMPLES / 2];
  IMU_roll_offset = roll_samples[CALIBRATION_SAMPLES / 2];
  IMU_pitch_rate_offset = pitch_rate_samples[CALIBRATION_SAMPLES / 2];
  IMU_roll_rate_offset = roll_rate_samples[CALIBRATION_SAMPLES / 2];
  IMU_yaw_rate_offset = yaw_rate_samples[CALIBRATION_SAMPLES / 2];

  Serial.println("Calibrated Values:");
  Serial.print("Pitch Rate Offset: ");
  Serial.println(IMU_pitch_rate_offset);
  Serial.print("Roll Rate Offset: ");
  Serial.println(IMU_roll_rate_offset);
  Serial.print("Yaw Rate Offset: ");
  Serial.println(IMU_yaw_rate_offset);
  Serial.print("Pitch Offset: ");
  Serial.println(IMU_pitch_offset);
  Serial.print("Roll Offset: ");
  Serial.println(IMU_roll_offset);

  turnOnLEDs();
  delay(1000);
  turnOffLEDs();

}

void findMedian(double* array, int n) {
    for (int i = 0; i < n - 1; i++) {     
        for (int j = 0; j < n - i - 1; j++) {
            if (array[j] > array[j + 1]) {
                double temp = array[j];
                array[j] = array[j + 1];
                array[j + 1] = temp;
            }
        }
    }
}

void loop() {
  // RECEIVE PACKETS
  if(millis() - timeLastMessage > 100) {
    Packet receivedPacket;
    if (wirelessPacket.receivePacket(receivedPacket, false)) {
      resetMode = false;
      timeLastMessage = millis();
      if(prevState != (State) receivedPacket.state) {
        countStateChange++;
        if(countStateChange >= 8) {
          state = (State) receivedPacket.state;
          prevState = (State) receivedPacket.state;
          countStateChange = 0;
        }
      }
      else {
        countStateChange = 0;
      }

      remoteThrottle = receivedPacket.throttle;
      remoteRoll = receivedPacket.roll;
      remotePitch = receivedPacket.pitch;
      remoteYaw = receivedPacket.yaw;
      pitchTrim = receivedPacket.trims[0];
      rollTrim = receivedPacket.trims[1];
      yawTrim = receivedPacket.trims[2];

      if(abs(remoteRoll) < 3) remoteRoll = 0;
      if(abs(remotePitch) < 3) remotePitch = 0;
      if(abs(remoteYaw) < 3) remoteYaw = 0;

      desired_pitch = map(remotePitch, 0, 255, -90, 90) + pitchTrim;
      desired_roll = map(remoteRoll, 0, 255, -90, 90) + rollTrim;
      desired_yaw_rate = map(remoteYaw, 0, 255, -20, 20) + yawTrim;

      Kp_roll = receivedPacket.Kp_roll;
      Ki_roll = receivedPacket.Ki_roll;
      Kd_roll = receivedPacket.Kd_roll;

      Kp_pitch = receivedPacket.Kp_pitch;
      Ki_pitch = receivedPacket.Ki_pitch;
      Kd_pitch = receivedPacket.Kd_pitch;

      Kp_yaw = receivedPacket.Kp_yaw;
      Ki_yaw = receivedPacket.Ki_yaw;
      Kd_yaw = receivedPacket.Kd_yaw;
    }
  }

  else {
    if (millis() - timeLastMessage > 5000) {
      timeLastMessage = millis();
      state = DISARMED;
    }
  }

  // IMU
  quad_data_t orientation;
  unsigned long nowIMU = millis();
  if ((ahrs->getQuadOrientation(&orientation))) {
    incoming_pitch_rate = orientation.pitch_rate - IMU_pitch_rate_offset;
    incoming_roll_rate = orientation.roll_rate - IMU_roll_rate_offset;
    incoming_yaw_rate = orientation.yaw_rate - IMU_yaw_rate_offset;

    incoming_pitch = orientation.pitch - IMU_pitch_offset;
    incoming_roll = orientation.roll - IMU_roll_offset;

    if(abs(incoming_pitch_rate) < 0.05) incoming_pitch_rate = 0.0;
    if(abs(incoming_roll_rate) < 0.05) incoming_roll_rate = 0.0;
    if(abs(incoming_yaw_rate) < 0.05) incoming_yaw_rate = 0.0;

    if(abs(incoming_pitch) < 1) incoming_pitch = 0.0;
    if(abs(incoming_roll) < 1) incoming_roll = 0.0;

    cf_pitch = gain * (cf_pitch + (incoming_pitch_rate * RAD_TO_DEG * (nowIMU - lastIMU) / 1000.0)) + ((1.0 - gain) * incoming_pitch);
    cf_roll = gain * (cf_roll + (incoming_roll_rate * RAD_TO_DEG * (nowIMU - lastIMU) / 1000.0)) + ((1.0 - gain) * incoming_roll);  
  
    lastIMU = nowIMU;
  }

  // PID Control
  error_pitch = cf_pitch - desired_pitch;
  error_roll = cf_roll - desired_roll;
  error_yaw = incoming_yaw_rate - desired_yaw_rate;

  sum_error_pitch += 0.5 * (error_pitch + last_error_pitch) * (millis() - lastPIDTime) / 1000.0;
  sum_error_roll += 0.5 * (error_roll + last_error_roll) * (millis() - lastPIDTime) / 1000.0;
  sum_error_yaw += 0.5 * (error_yaw + last_error_yaw) * (millis() - lastPIDTime) / 1000.0;

  derivative_error_pitch = (error_pitch - last_error_pitch) * 1000.0 / (millis() - lastPIDTime + 0.0001);
  derivative_error_roll = (error_roll - last_error_roll) * 1000.0 / (millis() - lastPIDTime + 0.0001);
  derivative_error_yaw = (error_yaw - last_error_yaw) * 1000.0 / (millis() - lastPIDTime + 0.0001);

  last_error_pitch = error_pitch;
  last_error_roll = error_roll;
  last_error_yaw = error_yaw;

  if(Ki_pitch < 0.001) sum_error_pitch = 0.0;
  if(Ki_yaw < 0.001) sum_error_yaw = 0.0;
  if(Ki_roll < 0.001) sum_error_roll = 0.0;
  if(remoteThrottle < 1) {
    sum_error_pitch = 0.0;
    sum_error_yaw = 0.0;
    sum_error_roll = 0.0;
  }

  double control_output_pitch = Kp_pitch * error_pitch + Ki_pitch * sum_error_pitch + Kd_pitch * derivative_error_pitch;
  double control_output_roll = Kp_roll * error_roll + Ki_roll * sum_error_roll + Kd_roll * derivative_error_roll;
  double control_output_yaw = Kp_yaw * error_yaw + Ki_yaw * sum_error_yaw + Kd_yaw * derivative_error_yaw;
  
  lastPIDTime = millis();

  switch (state) {
    case QUAD_RESET:
      spinMotors(0, 0, 0, 0);
      turnOffLEDs();
      break;

    case DISARMED:
      spinMotors(0, 0, 0, 0);
      turnOffLEDs();
      break;

    case ARMED:
      turnOnLEDs();
      spinMotors(remoteThrottle, round(control_output_roll), round(control_output_pitch), round(control_output_yaw));
      break;
  }

  // SEND PACKETS
  if(millis() - timeLastSent > 1000) {
    Packet packetToSend = {MAGIC_NUMBER_QUAD, 0, 0, 0, 0, 0.0, 0.0, 0.0, 0.0, 0.0, 0.0, 0.0, 0.0, 0.0, 0, {0}, 0, 0};
    packetToSend.state = state;
    if(resetMode) {
      packetToSend.state = QUAD_RESET;
    }
    packetToSend.batteryVoltage = readBatteryPercentage();
    packetToSend.checksum = wirelessPacket.calculateChecksum(packetToSend);
    wirelessPacket.sendPacket(packetToSend);
    timeLastSent = millis();
  }
}

// void spinMotors(int throttle, int control_output_roll, int control_output_pitch, int control_output_yaw) {
//   if(throttle < 5) {
//     analogWrite(MOTOR1, 0);
//     analogWrite(MOTOR2, 0);
//     analogWrite(MOTOR3, 0);
//     analogWrite(MOTOR4, 0);
//   }
//   else {
//     analogWrite(MOTOR1, min(max(0,throttle + control_output_roll - control_output_pitch - control_output_yaw),255));
//     analogWrite(MOTOR2, min(max(0,throttle + control_output_roll + control_output_pitch + control_output_yaw),255));
//     analogWrite(MOTOR3, min(max(0,throttle - control_output_roll + control_output_pitch - control_output_yaw),255));
//     analogWrite(MOTOR4, min(max(0,throttle - control_output_roll - control_output_pitch + control_output_yaw),255));
//   }

//   // Serial.print(min(max(0,throttle + control_output_roll - control_output_pitch - control_output_yaw),255));
//   // Serial.print(" ");
//   // Serial.print(min(max(0,throttle + control_output_roll + control_output_pitch + control_output_yaw),255));
//   // Serial.print(" ");
//   // Serial.print(min(max(0,throttle - control_output_roll + control_output_pitch - control_output_yaw),255));
//   // Serial.print(" ");
//   // Serial.println(min(max(0,throttle - control_output_roll - control_output_pitch + control_output_yaw),255));

// }

// void spinMotors(int throttle, int control_output_roll, int control_output_pitch, int control_output_yaw) {
//   if(throttle < 5) {
//     analogWrite(MOTOR1, 0);
//     analogWrite(MOTOR2, 0);
//     analogWrite(MOTOR3, 0);
//     analogWrite(MOTOR4, 0);
//   } else {
//     // Calculate the raw values for each motor
//     int motor1_val = throttle + control_output_roll - control_output_pitch - control_output_yaw;
//     int motor2_val = throttle + control_output_roll + control_output_pitch + control_output_yaw;
//     int motor3_val = throttle - control_output_roll + control_output_pitch - control_output_yaw;
//     int motor4_val = throttle - control_output_roll - control_output_pitch + control_output_yaw;

//     // Find the maximum value
//     int max_val = max(max(motor1_val, motor2_val), max(motor3_val, motor4_val));

//     // Check if we need to normalize
//     if (max_val > 255) {
//       float scale = 255.0 / max_val;
//       motor1_val = (int)(motor1_val * scale);
//       motor2_val = (int)(motor2_val * scale);
//       motor3_val = (int)(motor3_val * scale);
//       motor4_val = (int)(motor4_val * scale);
//     }

//     // Write the values to the motors, ensuring they're within the 0-255 range
//     analogWrite(MOTOR1, constrain(motor1_val, 0, 255));
//     analogWrite(MOTOR2, constrain(motor2_val, 0, 255));
//     analogWrite(MOTOR3, constrain(motor3_val, 0, 255));
//     analogWrite(MOTOR4, constrain(motor4_val, 0, 255));
//   }
// }

// void spinMotors(int throttle, int control_output_roll, int control_output_pitch, int control_output_yaw) {
//     if(throttle < 5) {
//         analogWrite(MOTOR1, 0);
//         analogWrite(MOTOR2, 0);
//         analogWrite(MOTOR3, 0);
//         analogWrite(MOTOR4, 0);
//     } else {
//         // Calculate the PID sum for each motor
//         int pid1 = control_output_roll - control_output_pitch - control_output_yaw;
//         int pid2 = control_output_roll + control_output_pitch + control_output_yaw;
//         int pid3 = -control_output_roll + control_output_pitch - control_output_yaw;
//         int pid4 = -control_output_roll - control_output_pitch + control_output_yaw;

//         // Find the maximum and minimum PID values
//         int max_pid = max(max(pid1, pid2), max(pid3, pid4));
//         int min_pid = min(min(pid1, pid2), min(pid3, pid4));

//         // Scale PID values if necessary
//         if (max_pid + throttle > 255 || min_pid + throttle < 0) {
//             float scale_factor;
//             if (max_pid + throttle > 255) {
//                 scale_factor = (255.0 - throttle) / max_pid;
//             } else {
//                 scale_factor = (0.0 - throttle) / min_pid;
//             }
            
//             pid1 *= scale_factor;
//             pid2 *= scale_factor;
//             pid3 *= scale_factor;
//             pid4 *= scale_factor;
//         }

//         // Calculate final motor values and constrain them
//         int motor1_val = constrain(throttle + pid1, 0, 255);
//         int motor2_val = constrain(throttle + pid2, 0, 255);
//         int motor3_val = constrain(throttle + pid3, 0, 255);
//         int motor4_val = constrain(throttle + pid4, 0, 255);

//         // Write the values to the motors
//         analogWrite(MOTOR1, motor1_val);
//         analogWrite(MOTOR2, motor2_val);
//         analogWrite(MOTOR3, motor3_val);
//         analogWrite(MOTOR4, motor4_val);
//     }
// }

void spinMotors(int throttle, int control_output_roll, int control_output_pitch, int control_output_yaw) {
    if (throttle < 5) {
        analogWrite(MOTOR1, 0);
        analogWrite(MOTOR2, 0);
        analogWrite(MOTOR3, 0);
        analogWrite(MOTOR4, 0);
    } else {
        // Calculate the PID sum for each motor
        int pid1 = control_output_roll - control_output_pitch - control_output_yaw;
        int pid2 = control_output_roll + control_output_pitch + control_output_yaw;
        int pid3 = -control_output_roll + control_output_pitch - control_output_yaw;
        int pid4 = -control_output_roll - control_output_pitch + control_output_yaw;

        // Find the maximum PID value
        int max_pid = max(max(pid1, pid2), max(pid3, pid4));

        int adjusted_throttle = throttle;

        // Adjust throttle if necessary to avoid saturation
        if (max_pid + throttle > 255) {
            adjusted_throttle = 255 - max_pid; // Directly calculate the adjusted throttle
        }

        // Calculate final motor values and constrain them
        int motor1_val = constrain(adjusted_throttle + pid1, 0, 255);
        int motor2_val = constrain(adjusted_throttle + pid2, 0, 255);
        int motor3_val = constrain(adjusted_throttle + pid3, 0, 255);
        int motor4_val = constrain(adjusted_throttle + pid4, 0, 255);

        // Write the values to the motors
        analogWrite(MOTOR1, motor1_val);
        analogWrite(MOTOR2, motor2_val);
        analogWrite(MOTOR3, motor3_val);
        analogWrite(MOTOR4, motor4_val);
    }
}


void setupSensor()  {
 if (!lsm.begin_I2C()) {
    Serial.println("Failed to find LSM6DSOX chip");
    while (1) {
      delay(10);
    }
  }
  _accel = lsm.getAccelerometerSensor();
  _gyro = lsm.getGyroSensor();
  ahrs = new Adafruit_Simple_AHRS(_accel, _mag, _gyro);
  lsm.setAccelRange(LSM6DS_ACCEL_RANGE_2_G);
  lsm.setGyroRange(LSM6DS_GYRO_RANGE_2000_DPS);
  lsm.setAccelDataRate(LSM6DS_RATE_208_HZ);
  lsm.setGyroDataRate(LSM6DS_RATE_208_HZ);
  lsm.setAccelCompositeFilter(LSM6DS_CompositeFilter_LPF2, LSM6DS_CompositeFilter_ODR_DIV_20);
}

void turnOnLEDs() {
  digitalWrite(LED_1, HIGH);
  digitalWrite(LED_2, HIGH);
  digitalWrite(LED_3, HIGH);
  digitalWrite(LED_4, HIGH);
  analogWrite(PRETTY_LEDS, 128);
}

void turnOffLEDs() {
  digitalWrite(LED_1, LOW);
  digitalWrite(LED_2, LOW);
  digitalWrite(LED_3, LOW);
  digitalWrite(LED_4, LOW);
  analogWrite(PRETTY_LEDS, 0);
}

int readBatteryPercentage() {
  int raw = analogRead(BAT_SENSE_PIN);
  return map(constrain(raw, lowerBatteryLimit, upperBatteryLimit), lowerBatteryLimit, upperBatteryLimit, 0, 100);
}

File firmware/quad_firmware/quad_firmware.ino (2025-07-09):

#include "radio.h"
#include <Wireless_Packet.h>
#include <Wire.h>
#include <Adafruit_Sensor.h>
#include <QuadClass_LSM6DSOX.h>
#include <Adafruit_Simple_AHRS.h>
Wireless_Packet wirelessPacket;
#define RAD_TO_DEG 57.295779513082320876798154814105

// REF DESIGN
// const int MOTOR1 = 8; // BLUE
// const int MOTOR2 = 3; // RED
// const int MOTOR3 = 4; // GREEN
// const int MOTOR4 = 5; // UN

// OUR QUADCOPTER
const int MOTOR1 = 8; // BLUE
const int MOTOR2 = 4; // RED
const int MOTOR3 = 3; // GREEN
const int MOTOR4 = 5; // UN

// PITCH
// Blue and Unmarked are front - negative direction of pitch
// Red and Green are back - positive direction of pitch
const int LED_1 = 16; 
const int LED_2 = 17; 
const int LED_3 = 18; 
const int LED_4 = 36;
const int PRETTY_LEDS = 34;
const int BAT_SENSE_PIN = A7;

const int lowerBatteryLimit = 490;
const int upperBatteryLimit = 887;

 // state
State state = DISARMED;
unsigned long timeLastMessage = millis();
unsigned long timeLastSent = millis();
bool resetMode = true;

// other variables
int remoteThrottle = 0;
int remoteRoll = 0;
int remotePitch = 0;
int remoteYaw = 0;
int countStateChange = 0;
State prevState = DISARMED;

// Create LSM9DS0 board instance.
QuadClass_LSM6DSOX lsm = QuadClass_LSM6DSOX();
Adafruit_Simple_AHRS *ahrs = NULL;
Adafruit_Sensor *_accel = NULL;
Adafruit_Sensor *_gyro = NULL;
Adafruit_Sensor *_mag = NULL;  // No Yaw orientation | Always NULL

// store initial angle for complementary filter
double cf_pitch = 0.0;
double cf_roll = 0.0;
double cf_yaw = 0.0;
double pitch_angle = 0.0;
double roll_angle = 0.0;
double yaw_angle = 0.0;
double IMU_pitch_offset = 0.0;
double IMU_roll_offset = 0.0;
double IMU_yaw_offset = 0.0;
double IMU_pitch_rate_offset = 0.0;
double IMU_roll_rate_offset = 0.0;
double IMU_yaw_rate_offset = 0.0;
double incoming_pitch = 0.0;
double incoming_roll = 0.0;
double incoming_yaw = 0.0;
double incoming_pitch_rate = 0.0;
double incoming_roll_rate = 0.0;
double incoming_yaw_rate = 0.0;
bool is_calib_IMU = false;
double gain = 0.95;


// PID
double Kp_roll = 0.0;
double Ki_roll = 0.0;
double Kd_roll = 0.0;

double Kp_pitch = 0.0;
double Ki_pitch = 0.0;
double Kd_pitch = 0.0;

double Kp_yaw = 0.0;
double Ki_yaw = 0.0;
double Kd_yaw = 0.0;

double desired_yaw = 0.0;
double desired_roll = 0.0;
double desired_pitch = 0.0;

double error_roll = 0.0;
double last_error_roll = 0.0;
double sum_error_roll = 0.0;

double error_pitch = 0.0;
double last_error_pitch = 0.0;
double sum_error_pitch = 0.0;

double error_yaw = 0.0;
double last_error_yaw = 0.0;
double sum_error_yaw = 0.0;

unsigned long lastPIDTime = millis();

void setup() {
  // Serial
  Serial.begin(115200);

  // Battery
  analogReference(INTERNAL);
  pinMode(BAT_SENSE_PIN, INPUT);

  // Motors
  pinMode(MOTOR1, OUTPUT);
  pinMode(MOTOR2, OUTPUT);
  pinMode(MOTOR3, OUTPUT);
  pinMode(MOTOR4, OUTPUT);

  // LEDs
  pinMode(LED_1, OUTPUT);
  pinMode(LED_2, OUTPUT);
  pinMode(LED_3, OUTPUT);
  pinMode(LED_4, OUTPUT);
  pinMode(PRETTY_LEDS, OUTPUT);

  // Radio
  rfBegin(RADIO_CHANNEL);

  // Setup the sensor gain and integration time.
  setupSensor();
}

unsigned long lastIMU = millis();

void loop() {
  // CODE TO READ IMU DATA
  //unsigned long initial_time = millis();
  quad_data_t orientation;
  unsigned long nowIMU = millis();
  
  // COMPLEMENTARY FILTER
  if ((nowIMU - lastIMU > 0) && (ahrs->getQuadOrientation(&orientation)))
  {
    incoming_pitch_rate = round(orientation.pitch_rate * 100) / 100.0  - IMU_pitch_rate_offset;
    incoming_roll_rate = round(orientation.roll_rate * 100) / 100.0  - IMU_roll_rate_offset;
    incoming_yaw_rate = round(orientation.yaw_rate * 100) / 100.0  - IMU_yaw_rate_offset;

    incoming_pitch = round(orientation.pitch * 100) / 100.0 - IMU_pitch_offset;
    incoming_roll = round(orientation.roll * 100) / 100.0 - IMU_roll_offset;

    pitch_angle = pitch_angle + (incoming_pitch_rate * RAD_TO_DEG * (nowIMU - lastIMU) / 1000.0);
    roll_angle = roll_angle + (incoming_roll_rate * RAD_TO_DEG * (nowIMU - lastIMU) / 1000.0);

    cf_pitch = gain * (cf_pitch + (incoming_pitch_rate * RAD_TO_DEG * (nowIMU - lastIMU) / 1000.0)) + ((1.0 - gain) * incoming_pitch);
    cf_roll = gain * (cf_roll + (incoming_roll_rate * RAD_TO_DEG * (nowIMU - lastIMU) / 1000.0)) + ((1.0 - gain) * incoming_roll);   
  
    lastIMU = nowIMU;

    // Serial.print(roll_angle);
    // Serial.print(F(" "));
    // Serial.print(cf_roll);
    // Serial.print(F(" "));
    // Serial.print(pitch_angle);
    // Serial.print(F(" "));
    // Serial.println(cf_pitch);
    // Serial.print(IMU_pitch_offset);
    // Serial.print(F(" "));
    // Serial.println(orientation.pitch);

  }

  error_pitch = cf_pitch - desired_pitch;
  sum_error_pitch = sum_error_pitch + error_pitch * (double)(millis() - lastPIDTime) / 1000.0;

  error_roll = cf_roll - desired_roll;
  sum_error_roll = sum_error_roll + error_roll * (double)(millis() - lastPIDTime) / 1000.0;

  if(abs(error_pitch) < 5) error_pitch = 0.0;
  if(abs(error_roll) < 5) error_roll = 0.0;
  
  if(abs(desired_yaw) < 3) {
    desired_yaw = 0.0;
  }

  error_yaw = incoming_yaw_rate - desired_yaw;

  if(abs(error_yaw) < 0.03) {
    error_yaw = 0.0;
  }
  sum_error_yaw = sum_error_yaw + error_yaw * (double)(millis() - lastPIDTime) / 1000.0;

  double control_output_pitch = Kp_pitch * error_pitch + Ki_pitch * sum_error_pitch + Kd_pitch * (error_pitch - last_error_pitch) * 1000.0 / ((double)(millis() - lastPIDTime) + 0.01);
  double control_output_yaw = Kp_yaw * error_yaw + Ki_yaw * sum_error_yaw + Kd_yaw * (error_yaw - last_error_yaw) * 1000.0 / ((double)(millis() - lastPIDTime) + 0.01);
  double control_output_roll = Kp_roll * error_roll + Ki_roll * sum_error_roll + Kd_roll * (error_roll - last_error_roll) * 1000.0 / ((double)(millis() - lastPIDTime) + 0.01);

  // Serial.print(error_roll);
  // Serial.print(F(" "));
  // Serial.print(sum_error_roll);
  // Serial.print(F(" "));
  // Serial.println(last_error_roll);
  
  last_error_roll = error_roll;
  last_error_pitch = error_pitch;
  last_error_yaw = error_yaw;

  lastPIDTime = millis();
  if(state == ARMED) spinMotors(remoteThrottle, int(control_output_roll), int(control_output_pitch), int(control_output_yaw));

  // Ki windup issues
  if(Ki_pitch < 0.001) sum_error_pitch = 0.0;
  if(Ki_yaw < 0.001) sum_error_yaw = 0.0;
  if(Ki_roll < 0.001) sum_error_roll = 0.0;
  if(remoteThrottle < 0.001) {
    sum_error_pitch = 0.0;
    sum_error_yaw = 0.0;
    sum_error_roll = 0.0;
  }
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
